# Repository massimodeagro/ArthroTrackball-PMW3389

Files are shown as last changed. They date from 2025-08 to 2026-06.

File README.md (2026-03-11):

# ArthroTrackball-PMW3389
3D printing, circuit design and code for the sensor-based ArtroTrackball system: an omnidirectional treadmill desgned for jumping spiders.

The system has been designed thanks to a [research grant from the Association for the Study of Animal behaviour (ASAB)](https://www.asab.org/research-grants) and to a [post-doc fellowship from the Accademia Nazionale dei Lincei](https://www.lincei.it/it/premi_borse/borsa-di-studio-post-dottorato-dott-giuseppe-guelfi-2025)

The system uses two [PMW3389 laser sensors](https://www.pixart.com/products-detail/4/PMW3389DM-T3QU) arranged in a non-coplanar fashon to calculate the rotation of the 38mm sphere around its center across the x, y and z axes. The SROM for the sensor is provided by Pixart. The code implemented to do so has been written following the algorithms described in [M. Kumagai and R. L. Hollis, "Development of a three-dimensional ball rotation sensing system using optical mouse sensors," 2011 IEEE International Conference on Robotics and Automation, Shanghai, China, 2011, pp. 5038-5043](https://ieeexplore.ieee.org/abstract/document/5979899).

Here two code are provided. One to be flashed on an Arduino Uno device, and the second to be written on a Raspberry Pi Pico. Code to interface with PMW3389 device has been modified from https://github.com/mrjohnk/PMW3389DM. The sensor also requires a breakout board. The sensor with the board can be bought from https://www.tindie.com/products/citizenjoe/pmw3389-motion-sensor/. The former code achieves speed of up to 400Hz, while the Pi only gets to 200Hz. Both solutions then provide the x, y and z rotations as comma separated signed float (positive for clockwise, negative for counterclockwise). Any serial reader can then be used to retrive the values. I have also written a python package (AtrhroTrackball) that implements a class which can read directly the system output and sincronize it with other systems (camera, monitor, etc.) The package will be released soon.

If you use this, please reference at least one of the papers where I have described the system and this repo as distributed in zenodo  (below a not-necessarily-updated list):

- [Beydizada, N., Cannone, F., Pekàr, S., Baracchi, D., De Agrò, M. Habituation to visual stimuli is independent of boldness in a jumping spider (2024) Animal Behaviour](https://doi.org/10.1016/j.anbehav.2024.04.010)
- [Loconsole, M., Ferrante, F., Giacomazzi, D., De Agrò, M. Independence and synergy of spatial attention in the two visual systems of jumping spiders (2024) Journal of Experimental Biology](https://doi.org/10.1242/jeb.246199)
- [De Agrò, M.,  Rößler D.C., Shamble, P.S. Eye-specific detection and a multi-eye integration model of biological motion perception (2024) Journal of Experimental Biology](https://doi.org/10.1242/jeb.247061)
- [De Agrò, M., Rößler, D. C., Kim, K., & Shamble, P. S. Perception of biological motion in point-light displays by jumping spiders. (2021) PLOS Biology](https://doi.org/10.1371/journal.pbio.3001172)

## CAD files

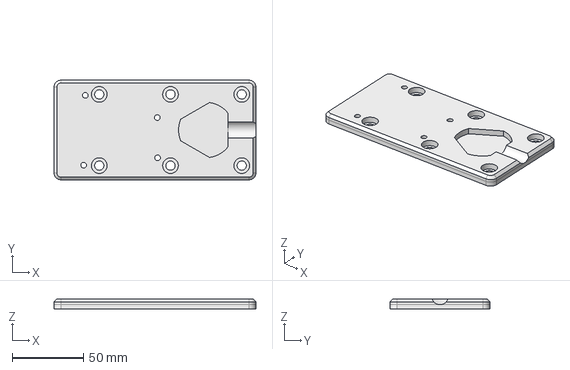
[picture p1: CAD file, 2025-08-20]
3Dprint/Base.step
141.8 x 70.0 x 7.00 mm

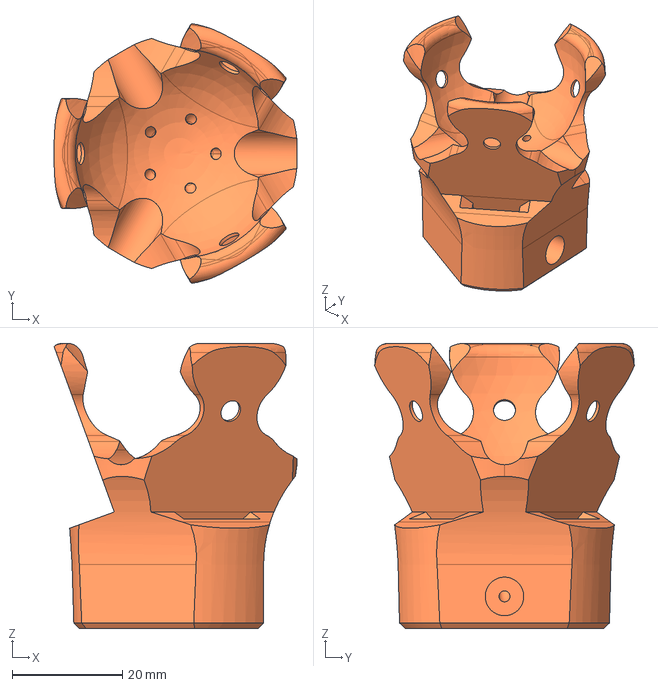
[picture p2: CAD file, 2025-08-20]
3Dprint/BallHolder.step
44.1 x 47.2 x 51.8 mm

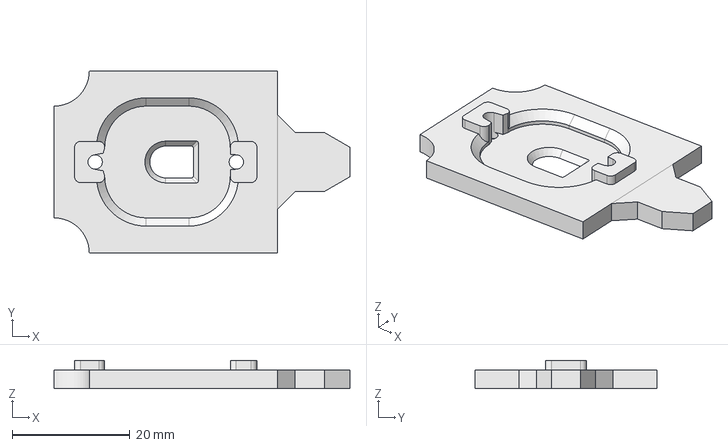
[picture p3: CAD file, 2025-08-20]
3Dprint/SensorHolder.step
50.3 x 31.0 x 4.80 mm

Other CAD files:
3Dprint/PWM3389Treadmill.FCStd

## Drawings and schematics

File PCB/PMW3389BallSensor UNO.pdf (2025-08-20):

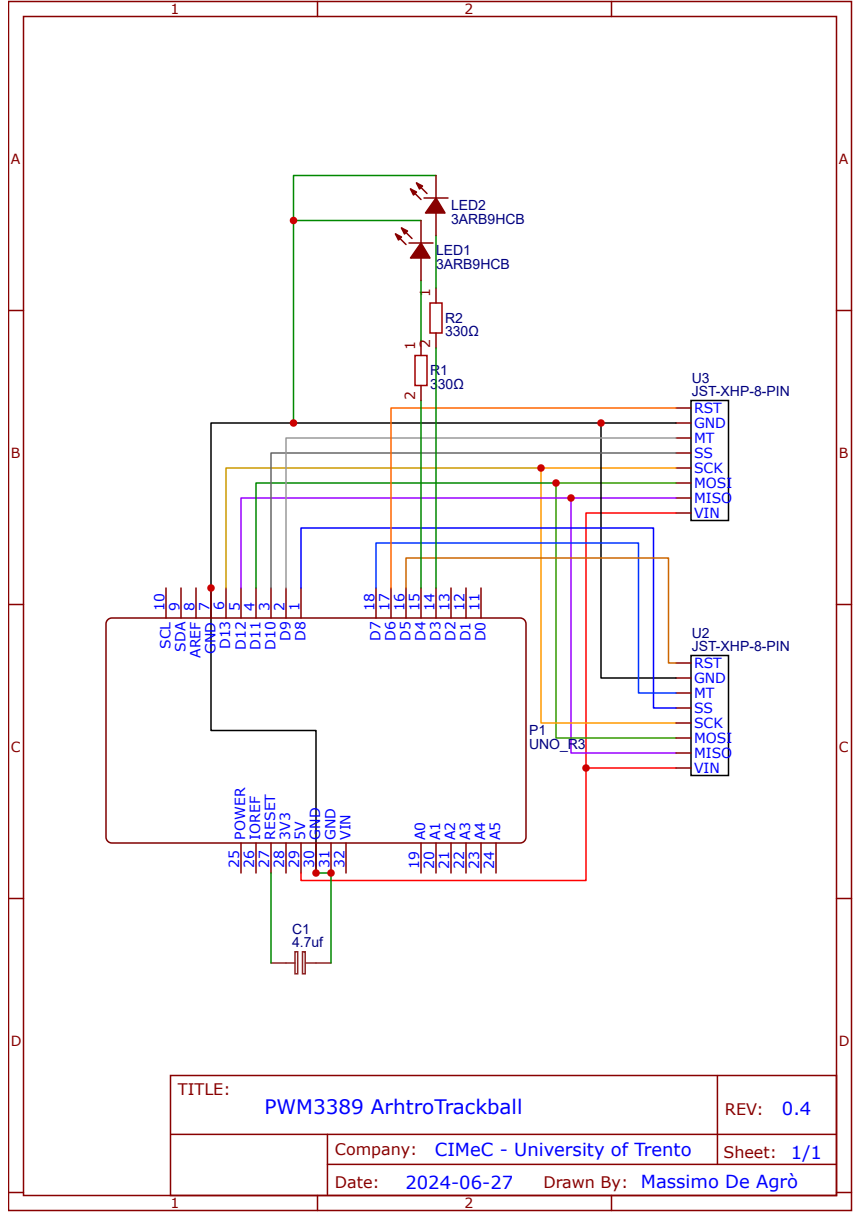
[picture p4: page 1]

Company: CIMeC - University of Trento

Drawn By: Massimo De Agrò

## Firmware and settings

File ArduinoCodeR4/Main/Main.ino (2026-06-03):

#include <SPI.h>
#include <avr/pgmspace.h>

// PMW3389 SPI Settings: Supports up to 2MHz clock speeds
SPISettings adnsSettings(2000000, MSBFIRST, SPI_MODE3);

// Registers
#define Product_ID  0x00
#define Revision_ID 0x01
#define Motion  0x02
#define Delta_X_L 0x03
#define Delta_X_H 0x04
#define Delta_Y_L 0x05
#define Delta_Y_H 0x06
#define SQUAL 0x07
#define Raw_Data_Sum  0x08
#define Maximum_Raw_data  0x09
#define Minimum_Raw_data  0x0A
#define Shutter_Lower 0x0B
#define Shutter_Upper 0x0C
#define Control 0x0D
#define Res_L 0x0E
#define Res_H 0x0F
#define Config2 0x10
#define Angle_Tune  0x11
#define Frame_Capture 0x12
#define SROM_Enable 0x13
#define Run_Downshift 0x14
#define Rest1_Rate_Lower  0x15
#define Rest1_Rate_Upper  0x16
#define Rest1_Downshift 0x17
#define Rest2_Rate_Lower  0x18
#define Rest2_Rate_Upper  0x19
#define Rest2_Downshift 0x1A
#define Rest3_Rate_Lower  0x1B
#define Rest3_Rate_Upper  0x1C
#define Observation 0x24
#define Data_Out_Lower  0x25
#define Data_Out_Upper  0x26
#define Raw_Data_Dump 0x29
#define SROM_ID 0x2A
#define Min_SQ_Run  0x2B
#define Raw_Data_Threshold  0x2C
#define Config5 0x2F
#define Power_Up_Reset  0x3A
#define Shutdown  0x3B
#define Inverse_Product_ID  0x3F
#define LiftCutoff_Tune3  0x41
#define Angle_Snap  0x42
#define LiftCutoff_Tune1  0x4A
#define Motion_Burst  0x50
#define LiftCutoff_Tune_Timeout 0x58
#define LiftCutoff_Tune_Min_Length  0x5A
#define SROM_Load_Burst 0x62
#define Lift_Config 0x63
#define Raw_Data_Burst  0x64
#define LiftCutoff_Tune2  0x65

#define PACKET_SCALE        100000   // radians * 100000 -

// Pin Maps
const int ncs0 = 10;
const int ncs1 = 8;
const int rst0 = 5;
const int rst1 = 6;

byte initComplete = 0;
unsigned long pollTimer = 0;
unsigned long lastMillis = 0;
const unsigned long LOOP_PERIOD_MICROS = 2000;
unsigned long lastLoopMicros = 0;

extern const unsigned short firmware_length;
extern const unsigned char firmware_data[];

// Sensors Geometric Configurations
const float res = 0.00508; // 5000 CPI Resolution multi-scale factor (25.4 / 5000)

float S0p[3]  = {15.26, 8.8, -6.4};
float S0xs[3] = {-0.5, 0.87, 0};
float S0ys[3] = {0.29, 0.18, 0.94};

float S1p[3]  = {-15.26, 8.8, -6.4};
float S1xs[3] = {-0.5, -0.87, 0};
float S1ys[3] = {-0.29, 0.18, 0.94};

// Map structural layout for clean indexing
struct AxisConfig {
    float* pos;
    float* dir;
};

AxisConfig sensorAxes[4] = {
    {S0p, S0xs}, // Index 0: Sensor 0 X
    {S0p, S0ys}, // Index 1: Sensor 0 Y
    {S1p, S1xs}, // Index 2: Sensor 1 X
    {S1p, S1ys}  // Index 3: Sensor 1 Y
};

// Map the specific index groups used by the 4 triplets
const uint8_t tripletAxesMapping[4][3] = {
    {0, 1, 2}, // Triplet 1
    {0, 1, 3}, // Triplet 2
    {1, 2, 3}, // Triplet 3
    {0, 2, 3}  // Triplet 4
};

struct TripletData {
    float Ainv[3][3];
    float absAdet;
    float w[3];
    float w2[3];
} triplets[4];

float avg_w[3];

// Math Helpers
void crossProduct(const float a[3], const float b[3], float result[3]) {
    result[0] = a[1] * b[2] - a[2] * b[1];
    result[1] = a[2] * b[0] - a[0] * b[2];
    result[2] = a[0] * b[1] - a[1] * b[0];
}

float calculate_Adet(const float A[3][3]) {
    return A[0][0] * (A[1][1] * A[2][2] - A[2][1] * A[1][2]) -
           A[0][1] * (A[1][0] * A[2][2] - A[2][0] * A[1][2]) +
           A[0][2] * (A[1][0] * A[2][1] - A[2][0] * A[1][1]);
}

bool calculate_Ainv(const float A[3][3], float Ainv[3][3], float det) {
    if (det == 0) return false;
    Ainv[0][0] = (A[1][1] * A[2][2] - A[2][1] * A[1][2]) / det;
    Ainv[0][1] = (A[0][2] * A[2][1] - A[0][1] * A[2][2]) / det;
    Ainv[0][2] = (A[0][1] * A[1][2] - A[0][2] * A[1][1]) / det;

    Ainv[1][0] = (A[1][2] * A[2][0] - A[1][0] * A[2][2]) / det;
    Ainv[1][1] = (A[0][0] * A[2][2] - A[0][2] * A[2][0]) / det;
    Ainv[1][2] = (A[1][0] * A[0][2] - A[0][0] * A[1][2]) / det;

    Ainv[2][0] = (A[1][0] * A[2][1] - A[2][0] * A[1][1]) / det;
    Ainv[2][1] = (A[2][0] * A[0][1] - A[0][0] * A[2][1]) / det;
    Ainv[2][2] = (A[0][0] * A[1][1] - A[1][0] * A[0][1]) / det;
    return true;
}

void computeTripletW(int t, const float readings[4]) {
    float vsi = readings[tripletAxesMapping[t][0]];
    float vsj = readings[tripletAxesMapping[t][1]];
    float vsk = readings[tripletAxesMapping[t][2]];

    for (int i = 0; i < 3; i++) {
        triplets[t].w[i] = triplets[t].Ainv[i][0] * vsi + triplets[t].Ainv[i][1] * vsj + triplets[t].Ainv[i][2] * vsk;
        float sum = fabs(triplets[t].Ainv[i][0] * vsi) + fabs(triplets[t].Ainv[i][1] * vsj) + fabs(triplets[t].Ainv[i][2] * vsk);
        triplets[t].w2[i] = (sum != 0.0f) ? fabs(triplets[t].w[i]) / sum : 0.0f;
    }
}

void calculate_combined_avg_w(float out_avg[3]) {
    float xn[3] = {0, 0, 0};
    float xd[3] = {0, 0, 0};

    for (int i = 0; i < 4; i++) {
        float det = triplets[i].absAdet;
        for (int axis = 0; axis < 3; axis++) {
            xn[axis] += det * triplets[i].w2[axis] * triplets[i].w[axis];
            xd[axis] += det * triplets[i].w2[axis];
        }
    }

    for (int axis = 0; axis < 3; axis++) {
        out_avg[axis] = (xd[axis] != 0) ? (xn[axis] / xd[axis]) : 0;
        if (isnan(out_avg[axis])) out_avg[axis] = 0;
    }
}

// Setup & Runtime Loop
void setup() {
    Serial.begin(115200);

    pinMode(ncs0, OUTPUT);
    pinMode(ncs1, OUTPUT);
    pinMode(rst0, OUTPUT);
    pinMode(rst1, OUTPUT);
    digitalWrite(ncs0, HIGH);
    digitalWrite(ncs1, HIGH);
    digitalWrite(rst0, HIGH);
    digitalWrite(rst1, HIGH);

    SPI.begin();

    // Matrix Initialization Engine Loop
    for (int t = 0; t < 4; t++) {
        float A[3][3];
        for (int row = 0; row < 3; row++) {
            uint8_t axisIdx = tripletAxesMapping[t][row];
            float crossRes[3];
            crossProduct(sensorAxes[axisIdx].pos, sensorAxes[axisIdx].dir, crossRes);
            A[row][0] = crossRes[0];
            A[row][1] = crossRes[1];
            A[row][2] = crossRes[2];
        }
        float det = calculate_Adet(A);
        triplets[t].absAdet = fabs(det);
        calculate_Ainv(A, triplets[t].Ainv, det);
    }

    bool s0_ok = performStartup(ncs0);
    delay(1000);
    bool s1_ok = performStartup(ncs1);
    delay(1000);
   
    digitalWrite(ncs0, HIGH);
    digitalWrite(ncs1, HIGH);

    if (s0_ok && s1_ok) {
        initComplete = 9;  
    } else if (s0_ok && !s1_ok) {
        initComplete = 1;
    } else if (!s0_ok && s1_ok) {
        initComplete = 2;  
    } else {
        initComplete = 0;
    }

    pollTimer = millis();
}

void loop() {
    while (micros() - lastLoopMicros < LOOP_PERIOD_MICROS) {
        // Non-blocking wait trap to lock frequency to exactly 300Hz
    }
    lastLoopMicros = micros(); // Capture the exact start time of this execution cycle

    unsigned long currentMillis = millis();
   
    // Calculate the integer delta since the last iteration
    uint16_t deltaMillis = (uint16_t)(currentMillis - lastMillis);
    lastMillis = currentMillis;

    int x0, y0, x1, y1;
    byte sq0, sq1;
    byte mot0, mot1;
    uint16_t shutter0, shutter1;

    // SPI burst reads
    readBurst(ncs0, &x0, &y0, &sq0, &mot0, &shutter0);
    readBurst(ncs1, &x1, &y1, &sq1, &mot1, &shutter1);

    float readings[4] = {
        x0 * res,
        y0 * res,
        x1 * res,
        y1 * res
    };

    for (int t = 0; t < 4; t++) {
        computeTripletW(t, readings);
    }

    calculate_combined_avg_w(avg_w);
   
    sendBinaryPacket(avg_w[0], avg_w[1], avg_w[2], x0, y0, x1, y1, sq0, sq1, mot0, shutter0, mot1, shutter1, deltaMillis);
}

// SPI Transactions Framework
void adns_com_begin(int ncs) {
    digitalWrite(ncs, LOW);
    SPI.beginTransaction(adnsSettings);
}

void adns_com_end(int ncs) {
    delayMicroseconds(1);
    digitalWrite(ncs, HIGH);
    SPI.endTransaction();
}

byte adns_read_reg(byte reg_addr, int ncs) {
    adns_com_begin(ncs);
    SPI.transfer(reg_addr & 0x7f);
    delayMicroseconds(35); // PMW3389 tSRAD delay min parameter
    byte data = SPI.transfer(0);
    delayMicroseconds(1);
    adns_com_end(ncs);
    delayMicroseconds(19);
    return data;
}

void adns_write_reg(byte reg_addr, byte data, int ncs) {
    adns_com_begin(ncs);
    SPI.transfer(reg_addr | 0x80);
    SPI.transfer(data);
    delayMicroseconds(20);
    adns_com_end(ncs);
    delayMicroseconds(100);
}

void adns_upload_firmware(int ncs) {
    adns_write_reg(Config2, 0x20, ncs);
    adns_write_reg(SROM_Enable, 0x1d, ncs);
    delay(10);
    adns_write_reg(SROM_Enable, 0x18, ncs);

    adns_com_begin(ncs);
    SPI.transfer(SROM_Load_Burst | 0x80);
    delayMicroseconds(15);

    for (int i = 0; i < firmware_length; i++) {
        byte c = pgm_read_byte(firmware_data + i);
        SPI.transfer(c);
        delayMicroseconds(15);
    }
    adns_com_end(ncs);
    delayMicroseconds(10);

    adns_read_reg(SROM_ID, ncs);
    adns_write_reg(Config2, 0x00, ncs);

    // Explicitly lock resolution configuration to 5000 CPI (5000 / 50 = 100 = 0x64)
    adns_write_reg(Res_H, 0x00, ncs);
    adns_write_reg(Res_L, 0x64, ncs);
}

bool performStartup(int ncs) {
    adns_com_end(ncs);
    adns_com_begin(ncs);
    adns_com_end(ncs);
    adns_write_reg(Power_Up_Reset, 0x5a, ncs);
    delay(50);
    adns_read_reg(Motion, ncs);
    adns_read_reg(Delta_X_L, ncs);
    adns_read_reg(Delta_X_H, ncs);
    adns_read_reg(Delta_Y_L, ncs);
    adns_read_reg(Delta_Y_H, ncs);
    adns_upload_firmware(ncs);
    delay(10);

    byte out = adns_read_reg(Product_ID, ncs);
    delay(1000);
    if (out == 0x47) {
        return true;
    }
    return false;
}

void readBurst(int ncs, int *dx, int *dy, byte *squal, byte *motionStatus, uint16_t *shutterSpeed) {
    adns_write_reg(Motion_Burst, 0x01, ncs);
    adns_com_begin(ncs);
    SPI.transfer(Motion_Burst);
    delayMicroseconds(35); // PMW3389 tSRAD delay parameter

    byte buf[12]; // Expanded from 7 to 12 to capture the full frame
    for (int i = 0; i < 12; i++) {
        buf[i] = SPI.transfer(0);
    }
    adns_com_end(ncs);

    // 1. Extract Motion status flag (Byte 0)
    *motionStatus = buf[0];

    // 2. Extract Delta X and Y (Bytes 2-5)
    *dx = (int)(int16_t)((buf[3] << 8) | buf[2]);
    *dy = (int)(int16_t)((buf[5] << 8) | buf[4]);

    // 3. Extract Surface Quality (Byte 6)
    *squal = buf[6];

    // 4. Extract Real-time Shutter Speed (Bytes 10 & 11)
    *shutterSpeed = (uint16_t)((buf[10] << 8) | buf[11]);
}

// Explicitly define packet size constants
#define RAW_PAYLOAD_SIZE 25
#define TRANSMIT_BUFFER_SIZE (RAW_PAYLOAD_SIZE + 2) // +1 for Checksum, +1 for COBS Overhead

void sendBinaryPacket(float wx, float wy, float wz, int x0, int y0, int x1, int y1,
                      byte sq0, byte sq1, byte mot0, uint16_t shutter0, byte mot1, uint16_t shutter1, uint16_t deltaMillis) {
   
    // 1. Constrain and cast safely to unsigned equivalents for bitwise operations
    uint16_t iwx = (int16_t)constrain((long)(wx * PACKET_SCALE), -32768, 32767);
    uint16_t iwy = (int16_t)constrain((long)(wy * PACKET_SCALE), -32768, 32767);
    uint16_t iwz = (int16_t)constrain((long)(wz * PACKET_SCALE), -32768, 32767);
    uint16_t ix0 = (int16_t)constrain((long)x0, -32768, 32767);
    uint16_t iy0 = (int16_t)constrain((long)y0, -32768, 32767);
    uint16_t ix1 = (int16_t)constrain((long)x1, -32768, 32767);
    uint16_t iy1 = (int16_t)constrain((long)y1, -32768, 32767);

    // Buffer for raw data + checksum
    byte raw_buf[RAW_PAYLOAD_SIZE + 1];

    // Pack raw bytes explicitly using logical masking
    raw_buf[0]  = initComplete;
    raw_buf[1]  = (iwx >> 8) & 0xFF;  raw_buf[2]  = iwx & 0xFF;
    raw_buf[3]  = (iwy >> 8) & 0xFF;  raw_buf[4]  = iwy & 0xFF;
    raw_buf[5]  = (iwz >> 8) & 0xFF;  raw_buf[6]  = iwz & 0xFF;
    raw_buf[7]  = (ix0 >> 8) & 0xFF;  raw_buf[8]  = ix0 & 0xFF;
    raw_buf[9]  = (iy0 >> 8) & 0xFF;  raw_buf[10] = iy0 & 0xFF;
    raw_buf[11] = (ix1 >> 8) & 0xFF;  raw_buf[12] = ix1 & 0xFF;
    raw_buf[13] = (iy1 >> 8) & 0xFF;  raw_buf[14] = iy1 & 0xFF;
    raw_buf[15] = sq0;
    raw_buf[16] = sq1;

    raw_buf[17] = (deltaMillis >> 8) & 0xFF;
    raw_buf[18] = deltaMillis & 0xFF;

    raw_buf[19] = mot0;
    raw_buf[20] = (shutter0 >> 8) & 0xFF;    raw_buf[21] = shutter0 & 0xFF;
    raw_buf[22] = mot1;
    raw_buf[23] = (shutter1 >> 8) & 0xFF;    raw_buf[24] = shutter1 & 0xFF;

    // 2. Compute Checksum over the payload
    byte ck = 0;
    for (int i = 0; i < RAW_PAYLOAD_SIZE; i++) {
        ck ^= raw_buf[i];
    }
    raw_buf[RAW_PAYLOAD_SIZE] = ck; // Store checksum at the end of raw payload

    // 3. Encode to COBS to eliminate all 0x00 bytes from data stream
    byte tx_buf[TRANSMIT_BUFFER_SIZE];
   
    uint8_t code_index = 0;
    uint8_t code = 1;
   
    for (int i = 0; i < (RAW_PAYLOAD_SIZE + 1); i++) {
        if (raw_buf[i] == 0x00) {
            tx_buf[code_index] = code;
            code_index = i + 1;
            code = 1;
        } else {
            tx_buf[i + 1] = raw_buf[i];
            code++;
            if (code == 0xFF) {
                tx_buf[code_index] = code;
                code_index = i + 1;
                code = 1; // Safeguard for long packets (not strictly hit here)
            }
        }
    }
    tx_buf[code_index] = code;

    // 4. Stream frame out with a unique, un-collidable 0x00 delimiter
    Serial.write(tx_buf, TRANSMIT_BUFFER_SIZE);
    Serial.write((uint8_t)0x00);
    }

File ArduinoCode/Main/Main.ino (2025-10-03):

/*
 * This example bypasses the hardware motion interrupt pin
 * and polls the motion data registers at a fixed interval
 */

#include <SPI.h>
#include <avr/pgmspace.h>

// Registers
#define Product_ID  0x00
#define Revision_ID 0x01
#define Motion  0x02
#define Delta_X_L 0x03
#define Delta_X_H 0x04
#define Delta_Y_L 0x05
#define Delta_Y_H 0x06
#define SQUAL 0x07
#define Raw_Data_Sum  0x08
#define Maximum_Raw_data  0x09
#define Minimum_Raw_data  0x0A
#define Shutter_Lower 0x0B
#define Shutter_Upper 0x0C
#define Control 0x0D
#define Res_L 0x0E
#define Res_H 0x0F
#define Config2 0x10
#define Angle_Tune  0x11
#define Frame_Capture 0x12
#define SROM_Enable 0x13
#define Run_Downshift 0x14
#define Rest1_Rate_Lower  0x15
#define Rest1_Rate_Upper  0x16
#define Rest1_Downshift 0x17
#define Rest2_Rate_Lower  0x18
#define Rest2_Rate_Upper  0x19
#define Rest2_Downshift 0x1A
#define Rest3_Rate_Lower  0x1B
#define Rest3_Rate_Upper  0x1C
#define Observation 0x24
#define Data_Out_Lower  0x25
#define Data_Out_Upper  0x26
#define Raw_Data_Dump 0x29
#define SROM_ID 0x2A
#define Min_SQ_Run  0x2B
#define Raw_Data_Threshold  0x2C
#define Config5 0x2F
#define Power_Up_Reset  0x3A
#define Shutdown  0x3B
#define Inverse_Product_ID  0x3F
#define LiftCutoff_Tune3  0x41
#define Angle_Snap  0x42
#define LiftCutoff_Tune1  0x4A
#define Motion_Burst  0x50
#define LiftCutoff_Tune_Timeout 0x58
#define LiftCutoff_Tune_Min_Length  0x5A
#define SROM_Load_Burst 0x62
#define Lift_Config 0x63
#define Raw_Data_Burst  0x64
#define LiftCutoff_Tune2  0x65


// functions


void crossProduct(float a[3], float b[3], float result[3]) {
  result[0] = a[1] * b[2] - a[2] * b[1];
  result[1] = a[2] * b[0] - a[0] * b[2];
  result[2] = a[0] * b[1] - a[1] * b[0];
}

void printMatrix(float matrix[3][3]) {
  for (int i = 0; i < 3; i++) {
    for (int j = 0; j < 3; j++) {
      //Serial.print(matrix[i][j]);
      //Serial.print(" ");
    }
    //Serial.println();
  }
}

float calculate_Adet(float A[3][3]) {
  float Adet = A[0][0] * (A[1][1] * A[2][2] - A[2][1] * A[1][2]) -
               A[0][1] * (A[1][0] * A[2][2] - A[2][0] * A[1][2]) +
               A[0][2] * (A[1][0] * A[2][1] - A[2][0] * A[1][1]);
  return Adet;
}

// to calculate the inverse of a 3x3 matrix
bool calculate_Ainv(float A[3][3], float Ainv[3][3]) {
  float Adet = calculate_Adet(A);
  
  if (Adet == 0) {
    return false; // Matrix is not invertible if determinant is zero
  }

  Ainv[0][0] = (A[1][1] * A[2][2] - A[2][1] * A[1][2]) / Adet;
  Ainv[0][1] = (A[0][2] * A[2][1] - A[0][1] * A[2][2]) / Adet;
  Ainv[0][2] = (A[0][1] * A[1][2] - A[0][2] * A[1][1]) / Adet;

  Ainv[1][0] = (A[1][2] * A[2][0] - A[1][0] * A[2][2]) / Adet;
  Ainv[1][1] = (A[0][0] * A[2][2] - A[0][2] * A[2][0]) / Adet;
  Ainv[1][2] = (A[1][0] * A[0][2] - A[0][0] * A[1][2]) / Adet;

  Ainv[2][0] = (A[1][0] * A[2][1] - A[2][0] * A[1][1]) / Adet;
  Ainv[2][1] = (A[2][0] * A[0][1] - A[0][0] * A[2][1]) / Adet;
  Ainv[2][2] = (A[0][0] * A[1][1] - A[1][0] * A[0][1]) / Adet;

  return true;
}

void calculate_w(float vsi, float vsj, float vsk, float Ainv[3][3], float w[3]) {

// calculate the w vector with matrix multiplication
w[0] = Ainv[0][0] * vsi + Ainv[0][1] * vsj + Ainv[0][2] * vsk;
w[1] = Ainv[1][0] * vsi + Ainv[1][1] * vsj + Ainv[1][2] * vsk;
w[2] = Ainv[2][0] * vsi + Ainv[2][1] * vsj + Ainv[2][2] * vsk;


}

void calculate_w_fast(float vsi, float vsj, float vsk, float Ainv[3][3], float w[3]) {
    #define MULT(i) Ainv[i][0] * vsi + Ainv[i][1] * vsj + Ainv[i][2] * vsk
    w[0] = MULT(0);
    w[1] = MULT(1);
    w[2] = MULT(2);
    #undef MULT
}

// Function to calculate w2 values
void calculate_w2(float vsi, float vsj, float vsk, float Ainv[3][3], float w2[3]) {
  
    float abs_sum = fabs(Ainv[0][0] * vsi) + fabs(Ainv[0][1] * vsj) + fabs(Ainv[0][1] * vsk);
    w2[0] = (abs_sum != 0) ? fabs(Ainv[0][0] * vsi + Ainv[0][1] * vsj + Ainv[0][2] * vsk) / abs_sum : 0;
    abs_sum = fabs(Ainv[1][0] * vsi) + fabs(Ainv[1][1] * vsj) + fabs(Ainv[1][1] * vsk);
    w2[1] = (abs_sum != 0) ? fabs(Ainv[1][0] * vsi + Ainv[1][1] * vsj + Ainv[1][2] * vsk) / abs_sum : 0;
    abs_sum = fabs(Ainv[2][0] * vsi) + fabs(Ainv[2][1] * vsj) + fabs(Ainv[2][1] * vsk);
    w2[2] = (abs_sum != 0) ? fabs(Ainv[2][0] * vsi + Ainv[2][1] * vsj + Ainv[2][2] * vsk) / abs_sum : 0;
}

void calculate_w2_fast(float vsi, float vsj, float vsk, float Ainv[3][3], float w2[3]) {
    #define CALC(i) \
        sum = fabs(Ainv[i][0] * vsi) + fabs(Ainv[i][1] * vsj) + fabs(Ainv[i][2] * vsk); \
        w2[i] = sum ? fabs(Ainv[i][0] * vsi + Ainv[i][1] * vsj + Ainv[i][2] * vsk) / sum : 0

    float sum;
    CALC(0);
    CALC(1);
    CALC(2);
    #undef CALC
}

// Function to calculate the weighted average of angular velocity
float calculate_avg_w(float ws[][3], float absAdets[], float w2s[][3], int num_triplets, float avg_w[3]) {
    float xn = 0;  // Numerators for wx, wy, wz
    float xd = 0;  // Denominators for wx, wy, wz
    float yn = 0;
    float yd = 0;
    float zn = 0;
    float zd = 0;

    // Loop through all triplets
    for (int i = 0; i < num_triplets; i++) {
        // Weighted sum for x, y, and z components
        xn += absAdets[i] * w2s[i][0] * ws[i][0];  // wx component
        xd += absAdets[i] * w2s[i][0];             // wx denominator

        yn += absAdets[i] * w2s[i][1] * ws[i][1];  // wy component
        yd += absAdets[i] * w2s[i][1];             // wy denominator

        zn += absAdets[i] * w2s[i][2] * ws[i][2];  // wz component
        zd += absAdets[i] * w2s[i][2];             // wz denominator
    }

    // Calculate final wx, wy, and wz (check for division by zero)
    float wx = (xd != 0) ? (xn / xd) : 0;
    float wy = (yd != 0) ? (yn / yd) : 0;
    float wz = (zd != 0) ? (zn / zd) : 0;

    // Check for NaN values (Arduino doesn't have std::isnan, so check for invalid values)
    if (isnan(wx)) wx = 0;
    if (isnan(wy)) wy = 0;
    if (isnan(wz)) wz = 0;

    // Update the last_avg_w array with the new weighted average
    avg_w[0] = wx;
    avg_w[1] = wy;
    avg_w[2] = wz;

}
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

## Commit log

2025-08-20 Insert Description README.md
2025-08-20 Add files via upload
    Added all files. Moving this from the main ArthroTrackball repository in order to have split repos for the device code and the python code
    [BallHolder.step, Base.step, PWM3389Treadmill.FCStd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]
2026-05-13 Add motion detection Arduino sketch for arduino uno R4
2026-06-03 Refactor loop timing and SPI transaction handling
